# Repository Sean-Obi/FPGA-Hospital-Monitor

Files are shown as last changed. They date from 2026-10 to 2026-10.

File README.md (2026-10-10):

# FPGA Hospital Monitor



A three-channel patient monitor built on an FPGA: **ECG and heart rate**,
**blood oxygen (SpO₂)** and **skin temperature**, shown on a hospital-style
display.

The sensors are bought modules. Everything after them — the ADC control,
the I²C bus master, filtering, baseline removal, beat detection, the
heart-rate divider, the ratio-of-ratios oximetry maths, temperature
conversion, and the serial link — is Verilog running on a Digilent
Cmod A7-35T. The laptop only draws what it is sent.

The beat detector is scored against cardiologist annotations from the
PhysioNet MIT-BIH Arrhythmia Database, so its accuracy is a measured figure
rather than an impression.

> **Not a medical device.** Hobby and education only. Do not use it for
> diagnosis or treatment.

---

## The signal chain

```
 electrodes          fingertip             skin
     |                   |                   |
  AD8232             MAX30102              TMP36
  amp + filters      red + IR LEDs,        10 mV / °C
  (bought)           18-bit ADC (bought)   (bought)
     |                   |                   |
     |                   |             op-amp buffer     <- needed, see Wiring
     |                   |                   |
     v                   v                   v
   XADC VAUX4         I²C bus             XADC VAUX12
     |                   |                   |
 xadc_reader       i2c_master           xadc_reader
 (2 channels,      max30102_driver      (same block)
  sequencer)           |                     |
     |             spo2_calc             temp_convert
     |             udiv (44-bit)             |
     |                   |                   |
 ecg_filter              |                   |
 baseline_remove         |                   |
 beat_detect             |                   |
 bpm_calc / bpm_div      |                   |
     |                   |                   |
     +-------------------+-------------------+
                         |
                  telemetry_uart        S/B/T/O messages, 115200 baud
                         |
                  scripts/ecg_monitor.py --port COMx
```

`buzzer` and `led_flash` hang off the `beat` pulse.

---

## What goes over the serial line

Every message is six characters: a tag, four decimal digits with leading
zeros, newline.

| Message | Meaning | How often |
|---|---|---|
| `S2048` | one raw ECG sample, 0–4095 | 500 / s |
| `B0075` | heart rate, BPM | once per beat |
| `T0345` | skin temperature, tenths of °C (34.5 °C) | 2 / s |
| `O0098` | SpO₂ percent. `O0000` = no finger. `O0999` = MAX30102 not responding | every 2.6 s |

Bandwidth: the sample stream is 500 × 6 × 10 = 30,000 bit/s; the rest is a
few messages a second. About 27 % of the 115,200 baud line.

Measured on hardware: 0 bad lines in 114,000 messages.

---

## Hardware

| Part | Notes |
|---|---|
| Digilent Cmod A7-35T | 48-pin DIP, has the XADC built in |
| AD8232 breakout | ECG front end. Run it at **3.3 V**, not 5 V |
| ECG electrode pads + 3-lead snap cable | the cable plugs into the AD8232's 3.5 mm jack |
| MAX30102 module | pulse oximeter, I²C. **Pull-up jumper must be on 3.3 V** — see below |
| TMP36 | analogue temperature sensor, TO-92 |
| MCP6002 or LM358 | dual op-amp, used as a unity-gain buffer for the TMP36 |
| 0.1 µF capacitor | decoupling for the TMP36 |
| Passive buzzer + 100–220 Ω resistor | magnetic types need a transistor instead |
| Full-size breadboard + male jumpers | the Cmod straddles the centre channel |

### The Cmod A7 pins this design uses

**Only two of the 48 DIP pins are power:** pin 24 (VU) and pin 25 (GND).
There is **no 3.3 V on the DIP header** — it is only on the Pmod socket.
With USB attached the board drives about 4.7 V *out* onto pin 24, which
would damage every sensor here. Power all three from Pmod JA pin 6 (or 12).

DIP pins 15 and 16 each pass through an on-board 2.32 kΩ / 1 kΩ divider,
so they accept **0 to 3.3 V** and present 0 to 1 V to the XADC. One ADC
count is therefore 3.32 V / 4096 = **0.81 mV** at the pin (measured: 4051
counts on the 3.28 V rail). The negative half of each pair (G2, J2) is
grounded on the board, so they are single-ended inputs. With nothing
connected, the 1 kΩ leg holds the pin at 0 V, so an unwired input reads 0.

### Wiring: AD8232 (ECG)

| AD8232 | Cmod A7 |
|---|---|
| 3.3V | Pmod JA pin 6 |
| GND | Pmod JA pin 5, or DIP pin 25 |
| OUTPUT | DIP pin 15 (`xa_p[0]`, package pin G3, VAUX4) |

Electrode cable into the 3.5 mm jack. IEC colours: **red** just below the
right collarbone, **yellow** just below the left collarbone, **green** on the
lower left ribs. On the soft flesh, not on the bone. If the R peak comes
out pointing down, swap red and yellow.

### Wiring: TMP36 (skin temperature) — needs the buffer

The TMP36 can only source **50 µA**. The Cmod's input divider draws about
**250 µA** at the voltages involved, so connected directly the sensor's
output collapses and the reading is garbage. A unity-gain op-amp buffer
in between fixes it: the op-amp copies the voltage and supplies the current.

```
   TMP36 (flat face towards you, legs down):   +Vs   Vout   GND

   +Vs  ─── Pmod JA 3.3 V        (0.1 µF from +Vs to GND, close to the sensor)
   GND  ─── GND
   Vout ─── op-amp IN+ (pin 3)

   MCP6002 / LM358, DIP-8, same pinout for both:
       pin 8  V+   ─── Pmod JA 3.3 V
       pin 4  V−   ─── GND
       pin 3  IN+  ─── TMP36 Vout
       pin 2  IN−  ─── pin 1   (output tied back to the inverting input = gain of 1)
       pin 1  OUT  ─── DIP pin 16  (`xa_p[1]`, package pin H2, VAUX12)
```

Tape the flat face of the TMP36 against skin with something over it to
insulate it from the air. Inner wrist works; armpit reads closer to core.
It reads **skin** temperature, typically 32–35 °C, and is labelled as such
on the display.

### Wiring: MAX30102 (SpO₂)

| MAX30102 | Cmod A7 |
|---|---|
| VIN | Pmod JA 3.3 V |
| GND | GND |
| SCL | DIP pin 2 (`scl`, package pin L3) |
| SDA | DIP pin 3 (`sda`, package pin A16) |
| INT | not used |

**Check the pull-up jumper.** Most of these modules have a three-pad
solder jumper that selects whether the I²C pull-ups go to 1.8 V or 3.3 V.
The FPGA's inputs need 2.0 V to read a logic high, so at 1.8 V nothing
works and nothing explains why. With the module powered, a multimeter from
SCL to GND must read about 3.3 V. If it reads 1.8 V, move the jumper, or
add 4.7 kΩ resistors from SCL and SDA to 3.3 V. The MAX30102's own pins are
rated to 6 V, so 3.3 V pull-ups are fine for it.

Finger on the sensor window, light pressure, keep still. The first reading
takes about 5 s (two 2.56 s blocks).

### Buzzer

DIP pin 1 (`buzzer`, package pin M3) → 100–220 Ω → buzzer **+**. Buzzer **−** to GND.

### Safety

Electrodes on your chest is a different risk category from a sensor
clipped on a finger.

- **Unplug the laptop charger while electrodes are attached.** USB to a
  mains-powered laptop puts you indirectly on mains equipment. Laptop on
  battery, board on USB.
- Use proper single-use ECG pads.
- **Do not power the board from batteries on DIP pin 24 while USB is
  connected.** The reference manual is explicit — "if you have a power
  source attached to the VU pin, you must disconnect it before attaching
  a USB host, or risk damaging it." Since USB carries the data, battery
  power is not an option for this project.
- Insert and remove the Cmod with USB unplugged. Nothing is live until
  USB goes in.

---

## The shield PCB (KiCad)

The breadboard works for bring-up, but three sensor modules, an op-amp and
a regulator on jumper wires is fragile and noisy. `hardware/` holds a KiCad
design for a shield the Cmod A7 plugs into, with everything else soldered
on. Two-layer, 80 × 75 mm, through-hole throughout so it can be built with
an iron.

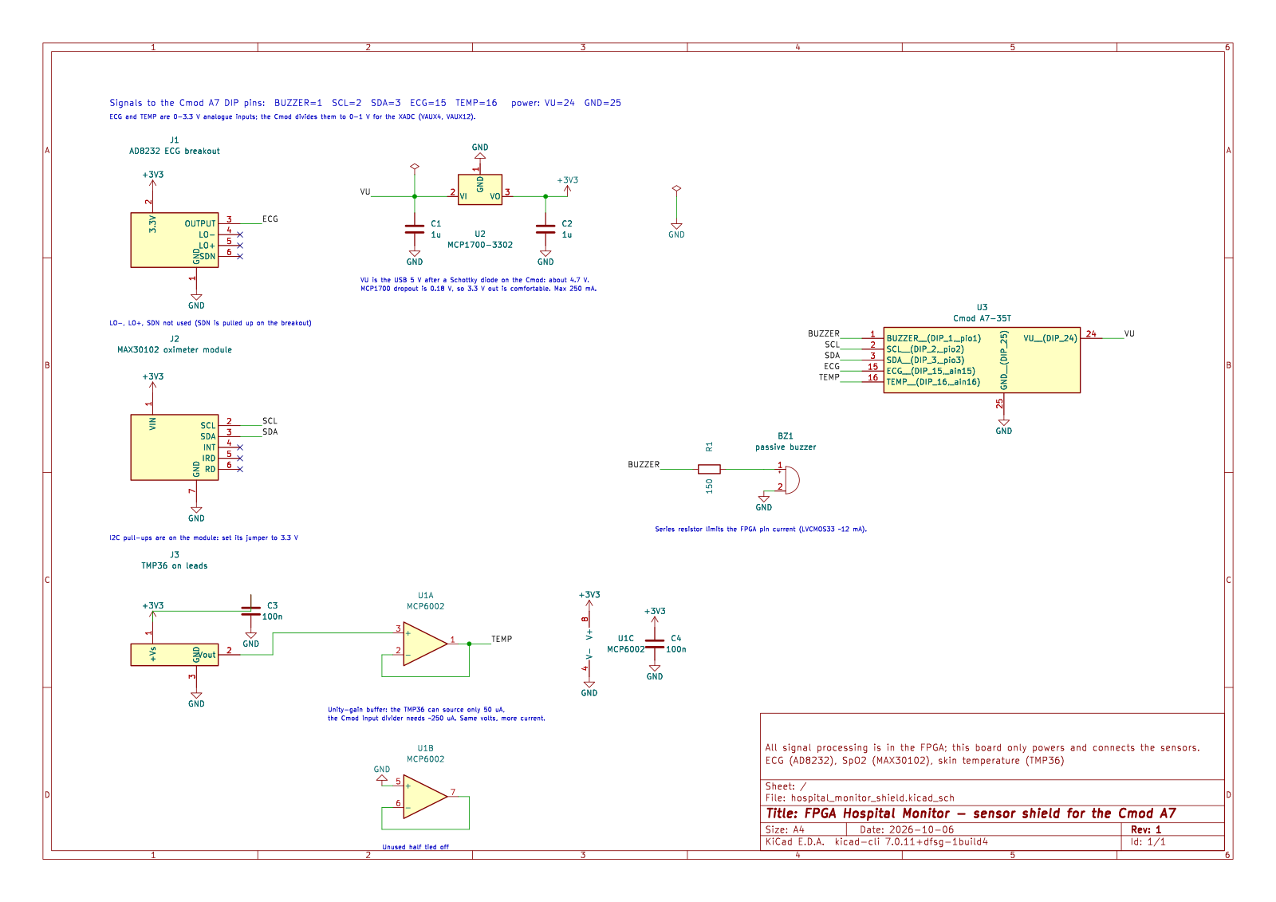
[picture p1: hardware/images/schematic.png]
Schematic


What is on it, and why:

| Ref | Part | Why |
|---|---|---|
| U3 | Cmod A7 socket, 2 × 24-pin female header, 0.6 in apart | the FPGA plugs in from above |
| U2, C1, C2 | MCP1700-3302 LDO, 2 × 1 µF | makes 3.3 V from VU (DIP pin 24, ~4.7 V), so no flying lead from the Pmod socket |
| J1 | 1 × 6 socket | the AD8232 breakout plugs in |
| J2 | 1 × 7 socket | the MAX30102 module plugs in |
| J3 | 1 × 3 socket | the TMP36 on a short lead, so it can be taped to skin |
| U1, C4 | MCP6002 dual op-amp, 100 nF | unity-gain buffer for the TMP36 (50 µA source limit vs the Cmod's 250 µA input divider); the spare half is tied off |
| C3 | 100 nF | decoupling at the TMP36 supply, as its datasheet asks |
| R1, BZ1 | 150 Ω, passive buzzer | beat beep; the resistor keeps the FPGA pin under its 12 mA rating |
| H1–H4 | M3 holes | so it can be stood off a desk or screwed into a case |

The analogue inputs stay single-ended into DIP pins 15 and 16, as on the
breadboard — the Cmod's own dividers do the scaling — so the Verilog needs
no change to run on the shield.

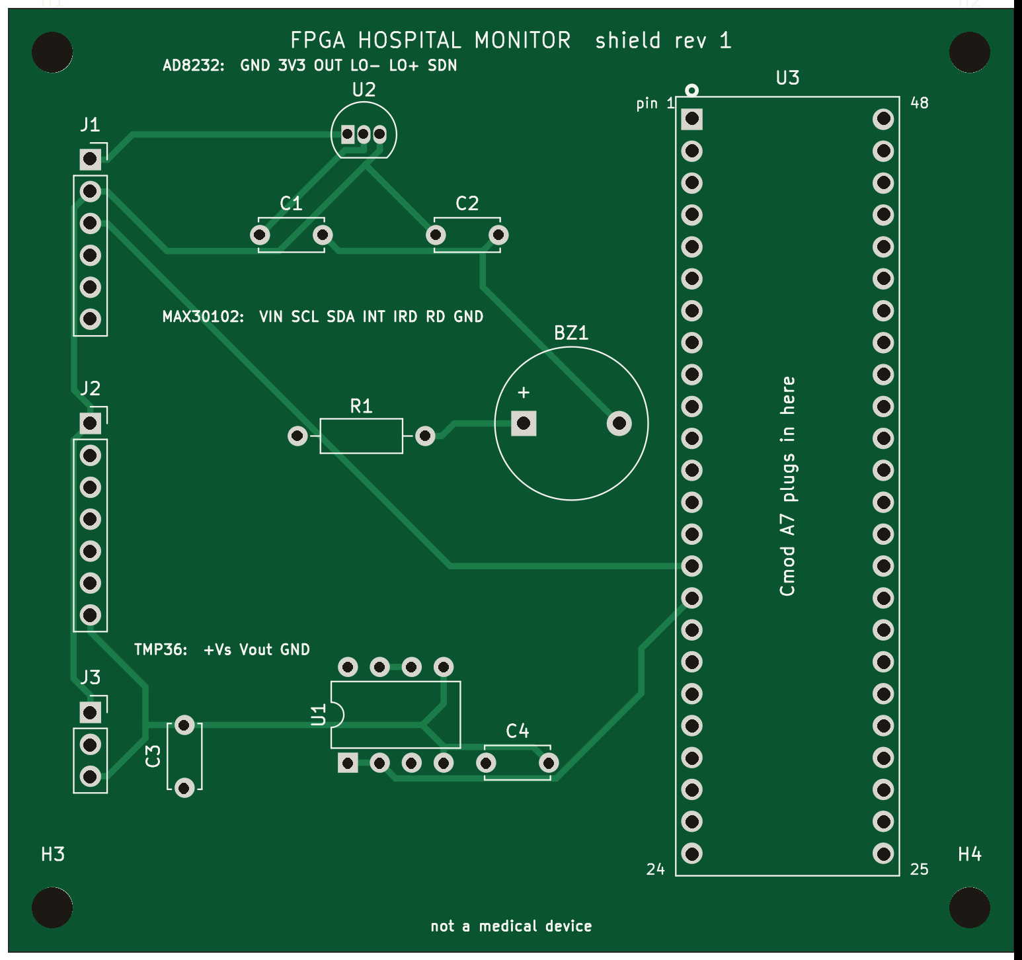
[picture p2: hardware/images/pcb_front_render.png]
PCB front


## How the numbers are worked out

### Heart rate

An 8-point moving average, baseline subtraction, then a threshold
crossing with a 250 ms refractory window so the T wave cannot be counted
as a second beat. The gap between beats in samples goes into a sequential
divider: BPM = 30000 / period.

### Temperature (fixed point, no floating point)

TMP36: 500 mV at 0 °C, 10 mV per °C — so **tenths of a degree = mV − 500**.
Pin: 0.8105 mV per count, written as **830 / 1024**. 256 readings are
summed and the maths is done on the sum, keeping the fractional part of the
average:

```
tenths = ((sum × 830) >> (10 + 8)) − 500
```

One ADC count is 0.08 °C; averaging 256 gives roughly 0.005 °C resolution.
A new value every 0.5 s. (`rtl/temp_convert.v`)

### SpO₂ (ratio of ratios)

Each light reading is a steady level (DC: tissue) plus a small wobble (AC:
blood pulsing). Oxygenated blood absorbs infrared more than red, so

```
       (AC_red / DC_red)
  R = -------------------          SpO₂ ≈ 110 − 25 R       (textbook linear fit)
       (AC_ir  / DC_ir)
```

Per block of 256 samples (2.56 s at 100 sps) and per colour: DC = sum >> 8,
AC = max − min. Then one 44-bit sequential division gives R scaled by 100,
and because 25/100 = 1/4:

```
  R100 = (AC_red × DC_ir × 100) / (DC_red × AC_ir)
  SpO₂ = (442 − R100) >> 2,  clamped to 0..100
```

"No finger" is an IR DC level below 30,000 counts. The linear fit is the
usual learning approximation; real oximeters use a curve calibrated on
volunteers. (`rtl/spo2_calc.v`, `rtl/udiv.v`)

### The MAX30102 driver

Bus recovery (9 clocks + STOP), software reset, read `PART_ID` (must be
0x15), configure — FIFO, ADC range 4096 nA, 100 sps, 411 µs pulses
(18-bit), both LEDs 6.2 mA, clear pointers, **mode last** — then poll the
FIFO write/read pointers every 2 ms and read six bytes per waiting sample.
Any NACK, wrong ID or stuck clock drops `sensor_ok`, waits a second and
starts again, so an unplugged sensor shows `ERR` rather than hanging.
(`rtl/max30102_driver.v`, `rtl/i2c_master.v`)

### Two ADC channels on one XADC

The XADC runs in continuous-sequence mode over VAUX4 and VAUX12. At each
end-of-conversion the channel number is latched and that channel's result
register is read over the DRP one clock later, so the two never get mixed
up. Both are then released together at 500 Hz. (`rtl/xadc_reader.v`)

---

## Software

| Tool | For |
|---|---|
| Vivado (free Standard edition) | building the bitstream |
| Icarus Verilog + GTKWave | simulation |
| Python 3.12 + `pyserial`, `pyqtgraph`, `PyQt6`, `numpy` | the live monitor |
| `wfdb`, `scipy` | PhysioNet playback and validation |

```
py -3.12 -m venv .venv312
.\.venv312\Scripts\Activate.ps1
python -m pip install pyserial pyqtgraph PyQt6 numpy wfdb scipy
```

Python 3.12, not 3.14: PyQt6 has no pre-built wheels for 3.14 yet and pip
will try to compile it and fail looking for `qmake`.

---

## Simulating (no board needed)

```
python scripts/run_all_sims.py
```

Builds and runs all 19 testbenches, about 70 seconds. Run it after
changing anything in `rtl/`. The top-level test feeds a synthetic ECG into
the XADC model, a synthetic pulse into the MAX30102 model, a known code
into the temperature channel, and decodes the serial line bit by bit like
the laptop would: 75 BPM, 35.0 °C and 98 % must all come out, then 0 with
the finger off and 999 with the oximeter unplugged.

| Testbench | Checks |
|---|---|
| `i2c_master_tb` | write/read with repeated START, auto-increment, NACK from an absent slave, stuck-SCL recovery |
| `max30102_driver_tb` | reset once, registers exactly as configured, mode written last, every sample delivered once, recovery when the sensor appears, wrong PART_ID rejected |
| `spo2_calc_tb` | exact DC/AC from known blocks; R = 0.5 → 98 %, 1.0 → 85 %, clamps, no finger, flat line, no divide-by-zero |
| `temp_convert_tb` | 617 → 0.0 °C, 1049 → 35.0 °C, clamps, averaging |
| `udiv_tb` | against Verilog's own `/`, including the widest SpO₂ operands and ÷0 |
| `xadc_reader_tb` | two channels never cross, every DRP read asks for the right register |
| `telemetry_uart_tb` | all four messages, priority order, nothing dropped at 500 Hz, same-clock collision |

Two stand-ins live in `tb/` and **must never be added to Vivado**:
`xadc_model.v` defines a module called `XADC` and would shadow the real
hardware block; `max30102_model.v` is the oximeter chip seen from its I²C
pins.

Each testbench was checked by deliberately breaking the module it tests
(swapped channels, inverted ACK, wrong byte order, reading the FIFO
unconditionally) and confirming the test failed.

To look at one in detail:

```
iverilog -g2012 -o build/top_sim tb/top_tb.v tb/xadc_model.v tb/max30102_model.v rtl/*.v
vvp build/top_sim
gtkwave top_tb.vcd
```

---

## Building for the board

1. New Vivado RTL project, part **xc7a35tcpg236-1** (or the Cmod A7-35T
   board file from the Xilinx Board Store).
2. Add every file in `rtl/`. Do **not** add anything from `tb/` or
   `practice/`.
3. Add `constraints/ecg_monitor.xdc` only. `Cmod-A7-Master.xdc` is kept
   for reference and is fully commented out, but there is no reason to add it.
4. Set `top` as the top module.
5. Generate Bitstream.
6. Open Hardware Manager → Open Target → Auto Connect, then **right-click
   `xc7a35t_0` → Program Device → Program**.

Step 6 is the one that gets missed. Setting the bitstream file and seeing
"Programmed" in the status column does **not** mean your design is loaded:
that column reflects the DONE pin, which is also high when the board boots
its factory demo from flash. The Tcl console must show
`program_hw_devices`. Programming is volatile — unplugging USB wipes it.

Vivado 2025.2 installs to `C:\AMDDesignTools\`, not `C:\Xilinx\`.

---

## Bring-up, in order

Each step assumes the one before it worked, so a failure tells you where
the problem is. The numbers are what this board measured.

**1. Does it run at all?** LD2 (`led[1]`) blinks at about 1.4 Hz. It
depends on nothing but the clock: if it blinks, the bitstream loaded, the
clock arrives and the pin constraints are right. LD0 (the RGB LED) stays
dark — if it is cycling colours you are running the factory demo, not this.

**2. Is the serial line working?**

```
python scripts/ecg_serial_monitor.py --list-ports
python scripts/ecg_serial_monitor.py --port COM4 --dump
```

Measured: 495–504 Hz (the wobble is Python's `sleep`, not the FPGA),
0 bad lines. With nothing on the analogue pin the samples read 0 or 1 —
the on-board divider holds it at ground, and the ±1 flicker is the ADC's
last bit, which is proof it is converting rather than frozen.

**3. Does the analogue input read a voltage?** One jumper from Pmod JA
pin 6 (3.3 V) to the breadboard row of DIP pin 15. Measured: **4051
counts**, i.e. 3.28 V — correct, and usefully *not* saturated at 4095, so
the gain is confirmed, not just the direction. Remove the jumper.

**4. Is the AD8232 alive?** Wire it (power + OUTPUT, no electrodes).
Measured: **2023–2030 counts** = 1.64 V, exactly half the 3.28 V rail,
with the same ±3 count noise as the bare pin.

**5. Electrodes on.** `python scripts/ecg_serial_monitor.py --port COM4`
— or the terminal plotter `python scripts/ascii_scope.py COM4` if the GUI
is not installed yet. You are looking for a recognisable trace.

Two tells that the electrodes are *not* connected to you, both seen on
this board before the pads were seated: peak-to-peak under ~50 counts of
structureless noise, and essentially **zero 50 Hz pickup** — a pad on skin
always picks up some mains hum, so silence at 50 Hz means an open
circuit. Pressing on the pads and tugging the leads should throw the trace
around; if it stays flat, the input is open. Check the 3.5 mm plug clicks
home, the snap studs are latched, the gel is moist (a drop of water
revives it), and the pads are on bare skin.

**6. Set the threshold.** Capture ten seconds with the pads on:

```
python -c "import serial,os; s=serial.Serial('COM4',115200,timeout=2); f=open('capture.txt','w'); [f.write(s.readline().decode(errors='replace')) for _ in range(5000)]; f.close(); print(os.path.getsize('capture.txt'))"
```

Read the R-peak height above baseline off it. `THRESHOLD` in `rtl/top.v`
should sit between the T wave and the R peak, roughly 40–50 % of the R
height. The default of 70 (57 mV at the AD8232 output) was chosen on a
simulated waveform; on the first real recording it caught roughly every
other beat, so it is likely too high. The validation sweep below is the
honest way to pick it.

**7. Temperature and SpO₂.** Wire the TMP36 (through the buffer) and the
MAX30102. `--dump` shows both:

```
   4478 samples    500.6 Hz   BPM  72   SpO2  98   temp  34.5 C   bad lines 0
```

`SpO2 ERR` = the MAX30102 is not acknowledging: check the jumper (step
above), SCL/SDA not swapped, 3.3 V on VIN. `SpO2 --` = no finger, or not
enough light coming back (press a little more firmly).

**8. The display.**

```
python scripts/ecg_monitor.py --port COM4
```

Buzzer and LD1 follow your pulse.

---

## Validation against PhysioNet

This is what makes the accuracy figure meaningful, and it needs no
hardware.

```
python scripts/make_ecg_hex.py --record 100 --seconds 60

iverilog -g2012 -o build/val_sim tb/validation_tb.v \
         rtl/heart_pipeline.v rtl/ecg_filter.v rtl/baseline_remove.v \
         rtl/beat_detect.v rtl/bpm_calc.v rtl/bpm_div.v \
         rtl/bpm_uart.v rtl/uart.v

vvp build/val_sim +samples=data/100_samples.hex +count=30000

python scripts/score_detection.py --record 100
```

Reports sensitivity, PPV and F1 against the cardiologist markings.

To choose the threshold from measurements rather than by eye:

```
python scripts/score_detection.py --record 100 --sweep 50 400 25
```

That rebuilds and re-runs at each threshold and prints a table.

No internet? `python scripts/make_ecg_hex.py --synthetic` makes a file
with the same layout so the flow can be tested offline. It is not a
substitute for real data.

---

## Known limitations

- The analogue front ends are bought modules; this project is about the
  digital design, not analogue circuit design.
- Single ECG lead.
- SpO₂ uses the linear 110 − 25R fit, not a calibrated curve, and reports
  on 2.56 s blocks with no outlier rejection. Motion ruins it, as it does
  on real oximeters.
- Temperature is skin temperature, not core.
- No leads-off detection on the ECG; the AD8232 provides `LO+`/`LO−` but
  nothing reads them.
- `xadc_reader` and `max30102_driver` are verified against behavioural
  models, not against silicon. The XADC sequencer configuration and the
  MAX30102 register values are the least-tested parts of the design.
- The shield PCB is designed and DRC-clean but has not been fabricated;
  every hardware measurement here is from the breadboard.

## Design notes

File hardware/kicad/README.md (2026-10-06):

# KiCad files

Open `hospital_monitor_shield.kicad_pro` in KiCad 7 or later.

| File | What |
|---|---|
| `hospital_monitor_shield.kicad_sch` | the schematic |
| `hospital_monitor_shield.kicad_pcb` | the board, routed, with a ground pour on the back |
| `ECG.pretty/CmodA7_DIP48.kicad_mod` | footprint for the Cmod A7 socket (two 1x24 female headers, 0.6 in apart) |
| `fp-lib-table` | tells KiCad where that footprint library is |

Both files are generated by the scripts in `../tools/` from a single
description, so the schematic and board cannot drift apart:

```
python hardware/tools/make_schematic.py
kicad-cli sch export netlist --format kicadsexpr -o build/shield.net hardware/kicad/hospital_monitor_shield.kicad_sch
python hardware/tools/make_pcb.py build/shield.net          # placement, rules, outline -> .kicad_pcb + .dsn
java -jar freerouting.jar -de build/shield.dsn -do build/shield.ses -mp 50
python hardware/tools/finish_pcb.py build/shield.ses        # tracks in, ground pour, DRC-ready
python hardware/tools/render_pcb.py                         # the green renders in ../images
```

The library symbols and footprints are copied into the files, so they
open without any extra libraries installed.

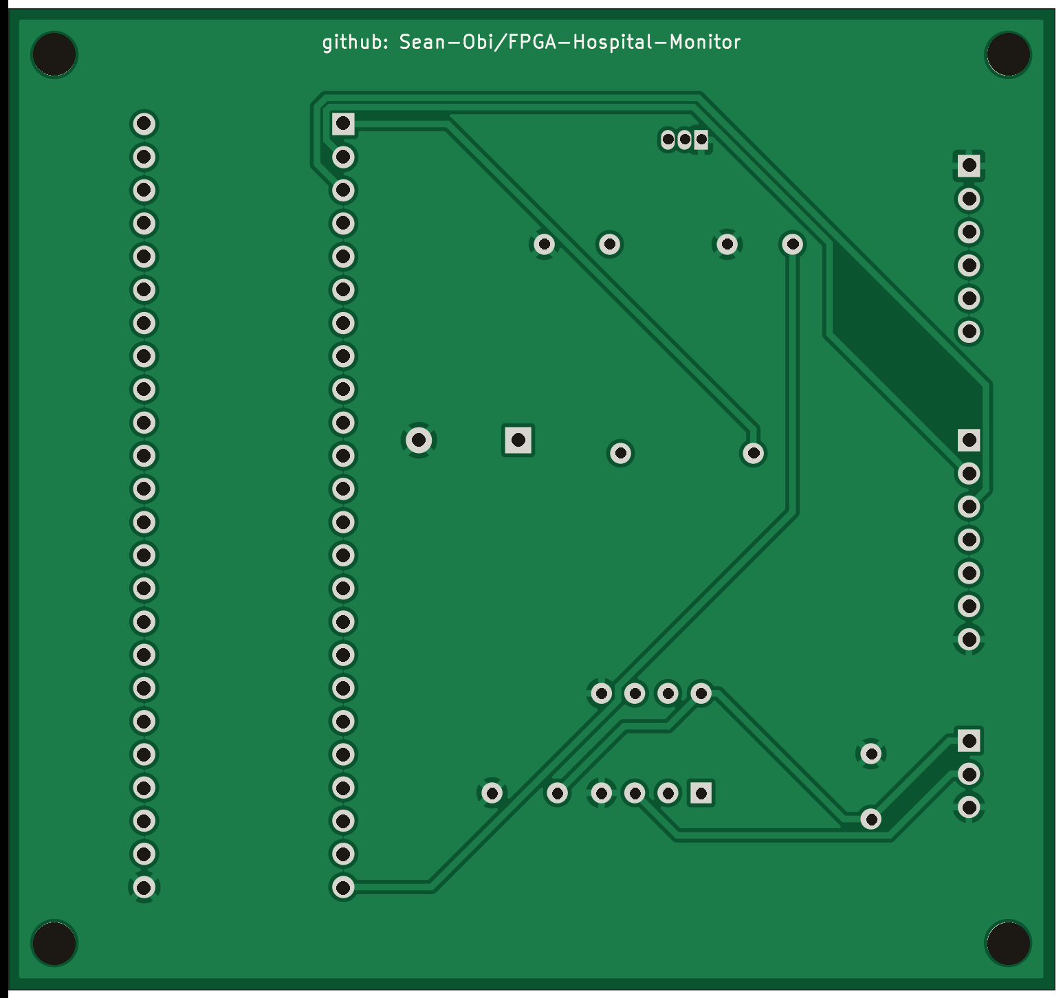
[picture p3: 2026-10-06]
hardware/images/pcb_back_render.png

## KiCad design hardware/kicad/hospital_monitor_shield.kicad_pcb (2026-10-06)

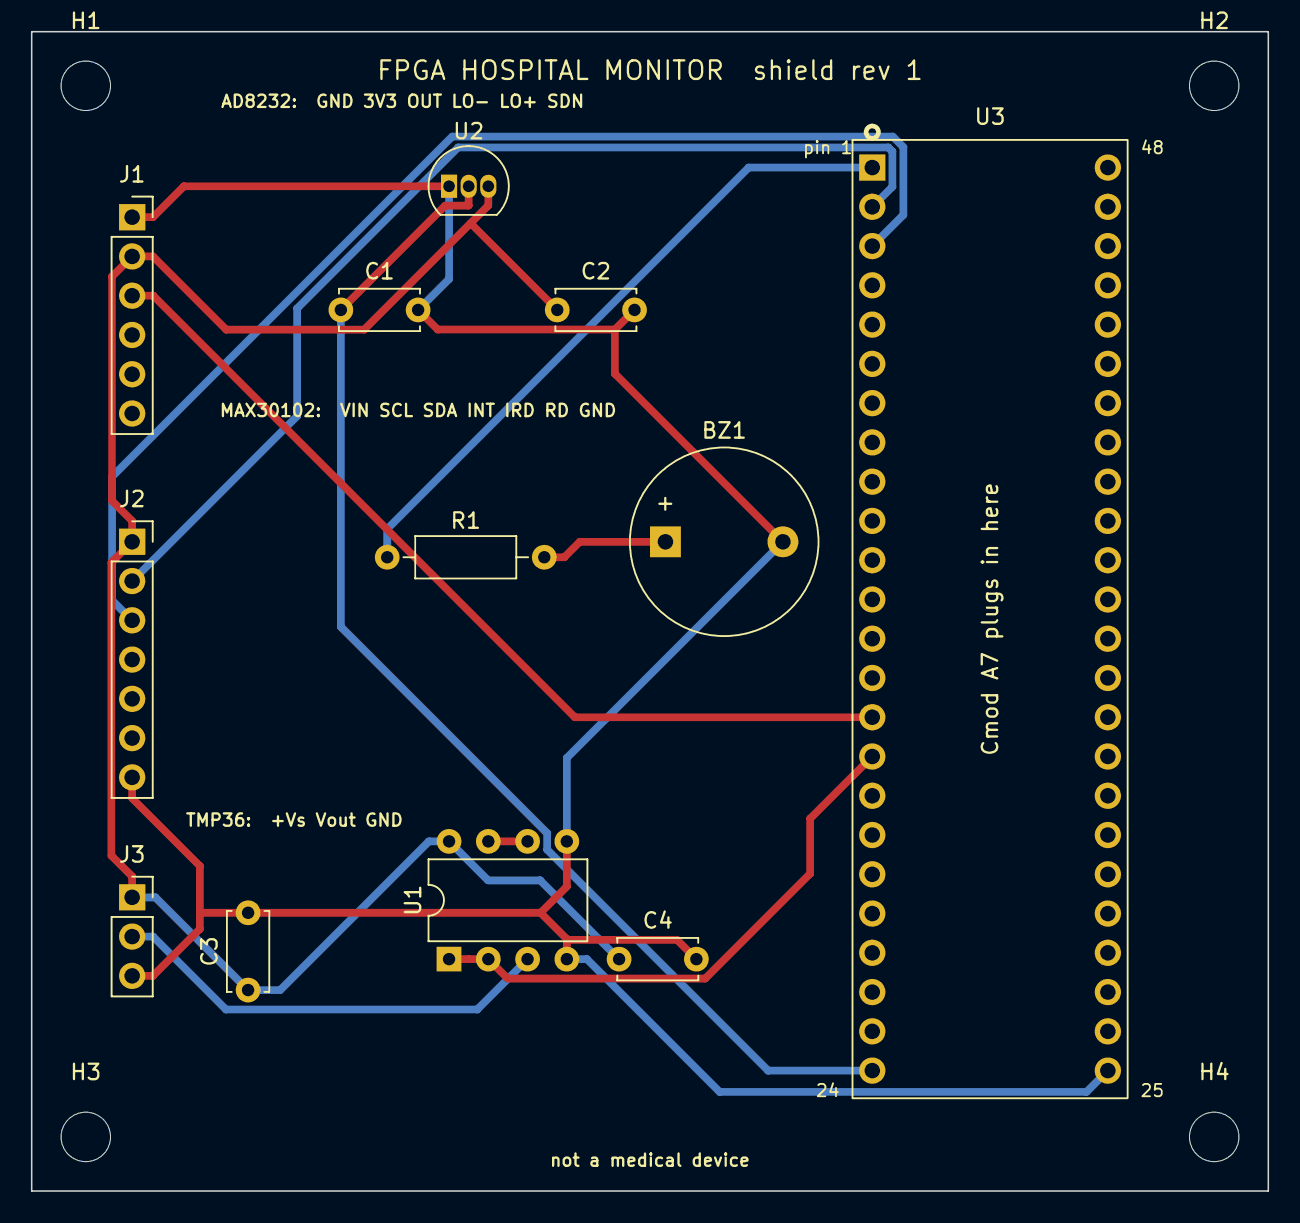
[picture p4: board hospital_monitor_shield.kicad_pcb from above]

Board: 2 copper layers, 80.0 x 75.0 mm, 16 parts (0 on the bottom side), 11 nets.

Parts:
BZ1: passive buzzer; Buzzer_12x9.5RM7.6
C1, C2: 1u; C_Disc_D5.0mm_W2.5mm_P5.00mm
C3, C4: 100n; C_Disc_D5.0mm_W2.5mm_P5.00mm
H1, H2, H3, H4: M3; MountingHole_3.2mm_M3
J1: AD8232 ECG breakout; PinSocket_1x06_P2.54mm_Vertical
J2: MAX30102 oximeter module; PinSocket_1x07_P2.54mm_Vertical
J3: TMP36 on leads; PinSocket_1x03_P2.54mm_Vertical
R1: 150; R_Axial_DIN0207_L6.3mm_D2.5mm_P10.16mm_Horizontal
U1: MCP6002; DIP-8_W7.62mm
U2: MCP1700-3302; TO-92_Inline
U3: Cmod A7-35T; CmodA7_DIP48

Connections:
+3V3: C2.1, C3.1, C4.1, J1.2, J2.1, J3.1, U1.8, U2.3
/BUZZER: R1.1, U3.1
/ECG: J1.3, U3.15
/SCL: J2.2, U3.2
/SDA: J2.3, U3.3
/TEMP: U1.1, U1.2, U3.16
/VU: C1.1, U2.2, U3.24
GND: BZ1.2, C1.2, C2.2, C3.2, C4.2, J1.1, J2.7, J3.3, U1.4, U1.5, U2.1, U3.25
unnamed: BZ1.1, R1.2
unnamed: J3.2, U1.3
unnamed: U1.6, U1.7

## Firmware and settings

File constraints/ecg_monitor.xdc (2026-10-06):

## ===========================================================
## FPGA ECG MONITOR - pin constraints for the Digilent Cmod A7-35T
##
## Taken from Cmod-A7-Master.xdc, with only the lines this
## design uses left in. Port names match top.v exactly, so
## nothing here needs renaming.
##
## Add BOTH this file and Cmod-A7-Master.xdc to a Vivado
## project and you will get duplicate-constraint errors.
## Use this one.
## ===========================================================


## -----------------------------------------------------------
## 12 MHz CLOCK
## -----------------------------------------------------------
##
## The second line tells Vivado how fast the clock runs, so it
## can check every path in the design is fast enough to keep up.
## Leave it out and Vivado has no idea, and will not warn you
## when something is too slow.
##
## 83.33 ns is one period of 12 MHz.

set_property -dict { PACKAGE_PIN L17   IOSTANDARD LVCMOS33 } [get_ports { sysclk }];
create_clock -add -name sys_clk_pin -period 83.33 -waveform {0 41.66} [get_ports { sysclk }];


## -----------------------------------------------------------
## LEDs
## -----------------------------------------------------------
##
## led[0]  flashes on every detected heartbeat
## led[1]  slow blink showing the design is running at all
##
## Both are needed: led is declared two bits wide in top.v, and
## Vivado will not place a design that has a port with no pin.

set_property -dict { PACKAGE_PIN A17   IOSTANDARD LVCMOS33 } [get_ports { led[0] }];
set_property -dict { PACKAGE_PIN C16   IOSTANDARD LVCMOS33 } [get_ports { led[1] }];


## -----------------------------------------------------------
## RESET BUTTON
## -----------------------------------------------------------
##
## btn[0] is the button nearest the USB connector.
##
## top.v assumes the button reads HIGH when pressed. If reset
## seems stuck on, or the button does nothing, that assumption
## is the thing to check - see the note in top.v.

set_property -dict { PACKAGE_PIN A18   IOSTANDARD LVCMOS33 } [get_ports { btn[0] }];


## -----------------------------------------------------------
## ANALOG INPUTS - ECG (AD8232) and temperature (TMP36)
## -----------------------------------------------------------
##
## These are DIP pins 15 and 16. Each passes through an on-board
## 2.32k / 1k divider, so 0..3.3 V at the pin becomes 0..1 V at
## the XADC. One ADC count = 0.81 mV at the pin.
##
## The XADC measures across a PAIR of pins, so both halves are
## declared even though only the P half carries a signal. The
## board grounds the N halves for you.
##
##   xa_p[0] = G3 = ain_p[15] = VAUX4   DIP 15  <- AD8232 OUTPUT
##   xa_n[0] = G2 = ain_n[15]
##   xa_p[1] = H2 = ain_p[16] = VAUX12  DIP 16  <- TMP36, via op-amp buffer
##   xa_n[1] = J2 = ain_n[16]

set_property -dict { PACKAGE_PIN G3    IOSTANDARD LVCMOS33 } [get_ports { xa_p[0] }];
set_property -dict { PACKAGE_PIN G2    IOSTANDARD LVCMOS33 } [get_ports { xa_n[0] }];
set_property -dict { PACKAGE_PIN H2    IOSTANDARD LVCMOS33 } [get_ports { xa_p[1] }];
set_property -dict { PACKAGE_PIN J2    IOSTANDARD LVCMOS33 } [get_ports { xa_n[1] }];


## -----------------------------------------------------------
## SERIAL OUT TO THE LAPTOP
## -----------------------------------------------------------
##
## The name looks backwards but is right. It is the RXD input
## of the USB-serial chip on the board, so from the FPGA's side
## it is an output. This carries the S/B/T/O messages.
##
## Open it at 115200 baud, 8 data bits, no parity, 1 stop bit.

set_property -dict { PACKAGE_PIN J18   IOSTANDARD LVCMOS33 } [get_ports { uart_rxd_out }];


## -----------------------------------------------------------
## BUZZER
## -----------------------------------------------------------
##
## This is the one line renamed from the master file. It was
## pio1 there; the design calls the signal "buzzer".
##
## M3 is pin 1 on the DIP header.
##
## Connect through a resistor. A piezo buzzer draws little
## enough to drive directly; a magnetic one needs a transistor
## and a flyback diode, so check what yours is first.

set_property -dict { PACKAGE_PIN M3    IOSTANDARD LVCMOS33 } [get_ports { buzzer }];


## -----------------------------------------------------------
## I2C TO THE MAX30102 PULSE OXIMETER
## -----------------------------------------------------------
##
## pio2 and pio3 in the master file; DIP pins 2 and 3, next to
## the buzzer on pin 1.
##
## I2C lines are open-drain: nothing ever drives them high, a
## pull-up resistor does. The MAX30102 module has its own
## pull-ups - make sure its solder jumper selects 3.3 V, not
## 1.8 V, or the FPGA will not see a logic high (LVCMOS33 needs
## 2.0 V). PULLUP true adds the FPGA's weak internal pull-up as
## well, which is a safety net rather than a substitute.
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

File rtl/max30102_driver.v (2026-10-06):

`default_nettype none

// ============================================================
// MODULE: max30102_driver
//
// PURPOSE:
//
// Runs the MAX30102 pulse oximeter chip over I2C and hands out
// one (red, infrared) light reading at a time.
//
// The MAX30102 shines a red LED and an infrared LED through your
// fingertip and measures how much light comes back. Blood that
// is carrying oxygen absorbs the two colours differently, so the
// ratio between the two signals says how saturated the blood is.
// This module only fetches the two numbers; spo2_calc.v does the
// maths.
//
// ------------------------------------------------------------
// WHAT IT DOES, IN ORDER
// ------------------------------------------------------------
//
//   1. Bus recovery: nine clock pulses and a STOP, in case the
//      chip was left mid-transfer by a previous bitstream.
//   2. Software reset (MODE_CONFIG bit 6), then wait 10 ms.
//   3. Read PART_ID. Must be 0x15, otherwise the thing on the
//      bus is not a MAX30102 and we stop and retry later.
//   4. Configure: FIFO, SpO2 ADC range / sample rate / pulse
//      width, LED currents, clear the FIFO pointers, and finally
//      switch to SpO2 mode.
//   5. Forever: read the FIFO write and read pointers. If they
//      differ, a sample is waiting: read six bytes from FIFO_DATA
//      and present them. Drain until the pointers match, then
//      wait a couple of milliseconds and look again.
//
// If anything fails (no ACK, PART_ID wrong, SCL stuck), sensor_ok
// drops, the driver waits a second and starts again from step 1.
// An unplugged sensor therefore shows up as sensor_ok = 0 rather
// than a hang, and plugging it in later just works.
//
// ------------------------------------------------------------
// WHY POLL THE POINTERS
// ------------------------------------------------------------
//
// The chip has an interrupt pin, but using it would mean another
// wire and another thing to get right on the breadboard. The two
// pointers tell us exactly how many samples are waiting, and
// reading them costs about 0.3 ms at 100 kHz - cheap against a
// 10 ms sample period.
//
// ------------------------------------------------------------
// THE SIX FIFO BYTES
// ------------------------------------------------------------
//
// In SpO2 mode every sample is RED then IR, three bytes each,
// MSB first, with the 18-bit value in the bottom 18 of 24 bits:
//
//     byte0[1:0] byte1[7:0] byte2[7:0]   = RED[17:0]
//     byte3[1:0] byte4[7:0] byte5[7:0]   = IR [17:0]
//
// Reading FIFO_DATA does not move the register pointer on to
// 0x08; it only advances the FIFO read pointer once all six
// bytes of a sample have been taken.
// ============================================================

module max30102_driver #(
    parameter integer CLK_HZ          = 12_000_000,
    parameter integer SCL_HZ          = 100_000,

    parameter integer RESET_WAIT_CLKS = CLK_HZ / 100,    // 10 ms
    parameter integer POLL_CLKS       = CLK_HZ / 500,    // 2 ms
    parameter integer RETRY_CLKS      = CLK_HZ,          // 1 s

    // Register values. See the datasheet, or the README.
    parameter [7:0]   FIFO_CONFIG     = 8'h10,   // no averaging, rollover on
    parameter [7:0]   SPO2_CONFIG     = 8'h27,   // 4096 nA, 100 sps, 411 us (18-bit)
    parameter [7:0]   LED_RED_PA      = 8'h1F,   // ~6.2 mA
    parameter [7:0]   LED_IR_PA       = 8'h1F
)(
    input  wire        clk,
    input  wire        reset,

    output reg  [17:0] red,
    output reg  [17:0] ir,
    output reg         sample_valid,     // one-clock pulse
    output reg         sensor_ok,        // high once PART_ID has been seen

    output wire        scl_oe,
    output wire        sda_oe,
    input  wire        scl_in,
    input  wire        sda_in
);


localparam [7:0] ADDR_W  = 8'hAE;   // 0x57 << 1
localparam [7:0] ADDR_R  = 8'hAF;
localparam [7:0] PART_ID = 8'h15;

localparam [7:0] REG_FIFO_WR  = 8'h04,
                 REG_FIFO_OVF = 8'h05,
                 REG_FIFO_RD  = 8'h06,
                 REG_FIFO_DAT = 8'h07,
                 REG_FIFO_CFG = 8'h08,
                 REG_MODE     = 8'h09,
                 REG_SPO2     = 8'h0A,
                 REG_LED1     = 8'h0C,
                 REG_LED2     = 8'h0D,
                 REG_PART_ID  = 8'hFF;


// ------------------------------------------------------------
// THE I2C MASTER
// ------------------------------------------------------------

localparam [1:0] CMD_START = 2'd0,
                 CMD_WRITE = 2'd1,
                 CMD_READ  = 2'd2,
                 CMD_STOP  = 2'd3;

reg        cmd_valid;
reg  [1:0] cmd;
reg  [7:0] wr_data;
reg        rd_ack;
wire       i2c_busy, i2c_done, i2c_ack, i2c_err;
wire [7:0] rd_data;

i2c_master #(
    .CLK_HZ (CLK_HZ),
    .SCL_HZ (SCL_HZ)
) u_i2c (
    .clk       (clk),
    .reset     (reset),
    .cmd_valid (cmd_valid),
    .cmd       (cmd),
    .wr_data   (wr_data),
    .rd_ack    (rd_ack),
    .busy      (i2c_busy),
    .done      (i2c_done),
    .rd_data   (rd_data),
    .ack_ok    (i2c_ack),
    .bus_error (i2c_err),
    .scl_oe    (scl_oe),
    .sda_oe    (sda_oe),
    .scl_in    (scl_in),
    .sda_in    (sda_in)
);


// ------------------------------------------------------------
// TRANSACTION ENGINE
// ------------------------------------------------------------
//
// Two kinds of transaction, built from the master's commands:
//
//   write register:  START  W(addr)  W(reg)  W(val)  STOP
//   read N bytes:    START  W(addr)  W(reg)  START  W(addr|1)
//                    R(ack) ... R(nack)  STOP
//
// The main state machine fills in x_kind / x_reg / x_val / x_n,
// pulses x_start, and waits for x_done. x_fail says whether
// anything went wrong on the way.

localparam [3:0] X_IDLE     = 4'd0,
                 X_START    = 4'd1,
                 X_ADDR     = 4'd2,
                 X_REG      = 4'd3,
                 X_VAL      = 4'd4,
                 X_RSTART   = 4'd5,
                 X_RADDR    = 4'd6,
                 X_RBYTE    = 4'd7,
                 X_STOP     = 4'd8,
                 X_RECOVER  = 4'd9;    // nine clocks with SDA free

reg [3:0]  x_state;
reg        x_start, x_done, x_fail;
reg        x_kind;                  // 0 = write, 1 = read
reg        x_recover;               // special: bus recovery
reg [7:0]  x_reg, x_val;
reg [2:0]  x_n;                     // bytes still to read
reg        waiting;                 // a command is in flight
reg        fail_pending;
reg [47:0] rx_buf;                  // the bytes read, newest at the bottom


// Issue one command to the master.
task issue(input [1:0] c, input [7:0] d, input a);
    begin
        cmd       <= c;
        wr_data   <= d;
        rd_ack    <= a;
        cmd_valid <= 1'b1;
        waiting   <= 1'b1;
    end
endtask
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

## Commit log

2026-10-06 Rename to FPGA Hospital Monitor, fab-style PCB renders
    [hospital_monitor_shield.kicad_pcb, hospital_monitor_shield.kicad_sch]
2026-10-06 Update README to remove unnecessary content
    Removed pinout diagram and PCB back image from README.
2026-10-19 Update README to remove transistor note for piezo
    Removed note about magnetic types needing a transistor.
